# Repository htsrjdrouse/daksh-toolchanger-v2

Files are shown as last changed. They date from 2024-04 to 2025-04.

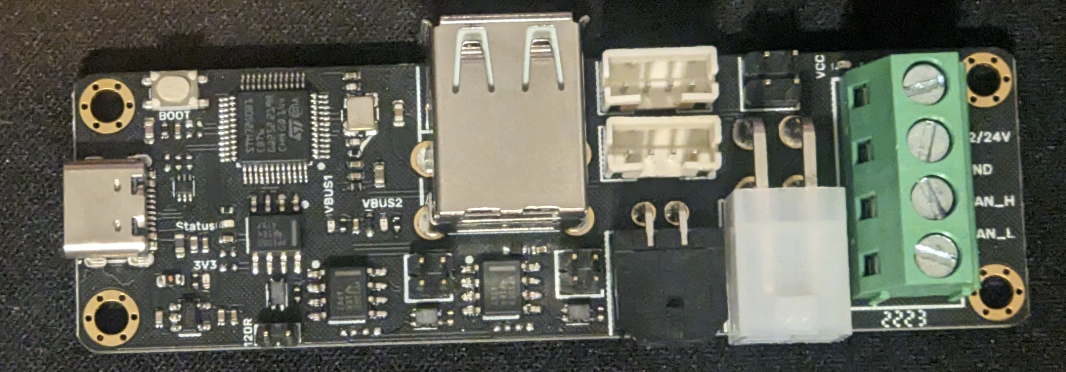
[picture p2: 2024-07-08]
Klipper/doc/btt_u2c_brd.png

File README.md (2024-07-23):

<b>Daksh modifications</b>

This version has a few modifications which were made in order to get it to work. The CAD design was modified using OpenScad and the code is included. Here is a list of various modifications:

1. Dock is modified so that it is rigid and accomodates the guide pins that adhere to the 2 in 1 rule for linear motion. The extruder assembly has been modified as well to match. There are more magnets to better secure the docking. 
2. Most (almost all) heat inserts have been replaced with self tapping holes.
3. Hall sensors have been replaced using mechanical endstops. This simplifies the wiring. 
4. The extruder has been redesigned to work with Bambu Labs hotend.
5. The z probe feature inside the extruder has been removed.
6. The maxwell coupling acorn nuts and mgn12 rails are 3-D printed.
7. The top rear extruder plate that secures the stepper motor has been redesigned that allows for better wiring organization.
8. Adjustable ooze wipes and adapted voron style spool holders

HTS Resources ToolChanger (https://www.youtube.com/watch?v=mFz-xJRdldU)

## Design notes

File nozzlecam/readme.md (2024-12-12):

This was originally a stroboscope but could be modified to work as a nozzlecam. It is based on the arducam. 



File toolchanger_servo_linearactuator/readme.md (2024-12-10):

Before working on this toolchanger project, I was focused on modifying 3D printers to function as liquid handlers for a laboratory automation applications. While doing this, I developed a tube loading/filling application that was apart of a nucleic acid detection assay which I documented <a href=https://www.htsresources.com/posts/Nucleic_acid_detection_PCR_Taqman_Probe_modified_3D_Printer/index.php> https://www.htsresources.com/posts/Nucleic_acid_detection_PCR_Taqman_Probe_modified_3D_Printer/index.php</a>. 

My interest with toolchangers is to create a "swiss army knife" of use case applications and I want to port over this application as being my first attempt to expand its utility. So I created a combined nozzle mount and linear actuator for the purposes of loading and unloading pipette tips. I haven't tested this design yet. While the original design employed a 8 pipette multichannel, this project involves focusing on a single nozzle.

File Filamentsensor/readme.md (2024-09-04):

The filament sensor is derived from https://www.printables.com/model/489791-smart-filament-sensor but modified to fit with the tool changer design. 

smart_filament_sensor_pic

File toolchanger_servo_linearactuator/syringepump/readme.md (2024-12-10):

I have been modifying the poseidon syringe pump (<a href=https://github.com/pachterlab/poseidon>https://github.com/pachterlab/poseidon</a>) So that it can work with a 1ml syringe pump.

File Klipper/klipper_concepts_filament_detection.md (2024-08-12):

# Filament sensors #

Testing the Sensors
1. Enable the sensors:
Run the macro TURN_ON_ALL_FILAMENT_SENSORS in your Klipper console.
2. Query individual sensors:
Use the QUERY_FILAMENT_SENSOR command with the sensor name:

```
QUERY_FILAMENT_SENSOR SENSOR=encoder_t0
QUERY_FILAMENT_SENSOR SENSOR=encoder_t1
```
3. Test sensor response:
Move filament through the sensor and run the query again to see if the state changes.

The code that controls this is filament_sensors.cfg. This is a set up for 2 tools. The key is to make sure TURN_ON_ALL_FILAMENT_SENSORS is in the start gcode. The PAUSE_AND_ALERT_FILAMENT macro will be modified so that PAUSE is changed to PAUSE_RESUME. ENABLE_FILAMENT_SENSOR is called by toolchanger.cfg through the gcode_macro SUB_TOOL_PICKUP_END. ENABLE_FILAMENT_SENSOR calls SET_FILAMENT_SENSOR which is a standard klipper function that is used to configure and control filament sensors, such as filament presence, detection, and runtime monitoring

```
[filament_motion_sensor encoder_t0]
switch_pin: EBB0: PB5
detection_length: 10
extruder: extruder
pause_on_runout: True
insert_gcode:
runout_gcode:
 PAUSE_AND_ALERT_FILAMENT T=0 STATE=JAM  

[filament_motion_sensor encoder_t1]
switch_pin: EBB1: PB5
detection_length: 10
extruder: extruder1
pause_on_runout: True
insert_gcode:
runout_gcode:
 PAUSE_AND_ALERT_FILAMENT T=1 STATE=JAM  

[gcode_macro TURN_ON_ALL_FILAMENT_SENSORS]
gcode:
        SET_FILAMENT_SENSOR SENSOR=encoder_t0 ENABLE=1
        SET_FILAMENT_SENSOR SENSOR=encoder_t1 ENABLE=1
        M118 ENABLE ALL FILAMENT_SENSORS

[gcode_macro TURN_OFF_ALL_FILAMENT_SENSORS]
gcode:
        SET_FILAMENT_SENSOR SENSOR=encoder_t0 ENABLE=0
        SET_FILAMENT_SENSOR SENSOR=encoder_t1 ENABLE=0
        M118 DISABLE ALL FILAMENT_SENSORS

[gcode_macro ENABLE_FILAMENT_SENSOR]
gcode:
  {% if params.T|int > 0 and params.T|int < 5 %}
         SET_FILAMENT_SENSOR SENSOR=encoder_t{params.T} ENABLE=1
         M118 ENABLE FILAMENT SENSOR T{params.T}
  {% endif %}

[gcode_macro PAUSE_AND_ALERT_FILAMENT]
gcode:
        M117 TOOLHEAD T{params.T} {params.STATE}
        SET_PAUSE_TYPE TYPE=2 # Set Pause Type to Filament
        SET_STATUS_LED_ERROR_START T={params.T}
        SET_ENCLOSURE_ERROR_START
        PAUSE
```

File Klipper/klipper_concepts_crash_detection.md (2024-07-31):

# Concepts about klipper programming environment as it relates to tool changing and crash_detection. #

Crash detection is important to ensure that the toolchanging is working, crash_detection.cfg controls this process, it is set up so that you can verify the toolchange during print after toolchanging after a specified time duration. 

## SAVE_GCODE_STATE ##

In Klipper, SAVE_GCODE_STATE is a command that saves the current state of the G-code parser, allowing the printer to resume a print job from the exact position where it was paused or interrupted.

When SAVE_GCODE_STATE is executed, Klipper saves the following information:

1. Current G-code line number
2. Current G-code command (e.g., G1, G28, etc.)
3. Current coordinates (X, Y, Z, E)
4. Current extruder temperature
5. Current bed temperature

This saved state allows Klipper to resume the print job from the exact position where it was paused or interrupted, ensuring that the print continues correctly.
SAVE_GCODE_STATE is typically used in conjunction with LOAD_GCODE_STATE to resume a print job after a pause or interruption. The workflow is as follows:
SAVE_GCODE_STATE saves the current state before pausing or interrupting the print.
The print is paused or interrupted (e.g., due to a tool change, error, or manual pause).
LOAD_GCODE_STATE loads the saved state, restoring the printer to the exact position where it was paused or interrupted.
The print resumes from the loaded state.
By using SAVE_GCODE_STATE and LOAD_GCODE_STATE, Klipper ensures that print jobs can be resumed accurately and reliably, even after interruptions or pauses.

SAVE_GCODE_STATE is called gcode_macros.cfg, toolchanger.cfg, klipper_toolchanger/M600.cfg and klipper_toolchanger/pause_resume.cfg: 

### gcode_macros.cfg ###

```
gcode_macros.cfg:    SAVE_GCODE_STATE NAME=PRIME_LINE_state
gcode_macros.cfg:    SAVE_GCODE_STATE NAME=BEFORE_CLEAN
gcode_macros.cfg:    SAVE_GCODE_STATE NAME=PURGE_state
```

### klipper_toolchanger/M600.cfg ###

```
klipper_toolchanger/M600.cfg:  SAVE_GCODE_STATE NAME=M600_state
```

### klipper_toolchanger/pause_resume.cfg ###

```
klipper_toolchanger/pause_resume.cfg:   SAVE_GCODE_STATE NAME=PAUSE_state
klipper_toolchanger/pause_resume.cfg:	 	SAVE_GCODE_STATE NAME=PAUSE_state
```

### toolchanger.cfg ###

```
toolchanger.cfg:  SAVE_GCODE_STATE NAME=tool_unlock_state                                         # Save gcode state
toolchanger.cfg:  SAVE_GCODE_STATE NAME=tool_lock_state                                           # Save gcode state
toolchanger.cfg:  SAVE_GCODE_STATE NAME=TOOL_PICKUP                                    # Save GCODE state. Will be restored at the end of SUB_TOOL_PICKUP_END
toolchanger.cfg:  SAVE_GCODE_STATE NAME=TOOL_DROPOFF_002                        # Save GCode state. 
```

LOAD_GCODE_STATE is not used in this software. 

## VERIFY_TOOLCHANGE_DURING_PRINT DURATION=30 FORCE=0 ##

In Klipper, when DURATION is specified in a command like VERIFY_TOOLCHANGE_DURING_PRINT DURATION=30 FORCE=0, it defines the verification window during which Klipper monitors the tool change process.
Here's how it works:

When the VERIFY_TOOLCHANGE_DURING_PRINT command is executed, Klipper starts monitoring the tool change process.

The DURATION parameter (in this case, 30 seconds) specifies the time window during which Klipper will verify the tool change.

The printer does not pause during this verification window. Instead, Klipper monitors the tool change process concurrently while the printer continues to move and execute G-code commands.

Within the 30-second verification window, Klipper checks the tool change status (e.g., sensor readings, tool presence, etc.) to ensure the tool change is successful.

If the verification fails within the 30-second window (e.g., sensors indicate an error), Klipper will pause the print and wait for manual intervention (due to FORCE=0).

In summary, the DURATION parameter defines the time window during which Klipper verifies the tool change process, but it does not cause the printer to pause. The verification occurs concurrently with the print job, allowing the printer to continue moving while Klipper monitors the tool change.

So if you printer is fails after loading and docking tools you may want to extend the DURATION. 

FORCE=0: This parameter controls the behavior if the tool change verification fails. A value of 0 means that if the verification fails, the print will pause and wait for manual intervention to resume. If FORCE were set to 1, the print would abort instead of pausing.

```
[gcode_macro VERIFY_TOOLCHANGE_DURING_PRINT]
        gcode:
                M118 "VERIFY_TOOLCHANGE_DURING_PRINT in {params.DURATION} seconds with printer state: {printer.idle_timeout.state} FORCE: {params.FORCE}"
                {% if printer.idle_timeout.state == "Printing" or params.FORCE|int == 1 %}
                        M118 "EXECUTING VERIFY_TOOLCHANGE_DURING_PRINT in {params.DURATION} seconds"
                        UPDATE_DELAYED_GCODE ID=_DELAYED_CHECK_MACHINE_STATE_QUICK DURATION=0
                        UPDATE_DELAYED_GCODE ID=_DELAYED_CHECK_MACHINE_STATE_QUICK DURATION={params.DURATION}
                {% endif %}
```

Let's break down this macro:

Macro Name: VERIFY_TOOLCHANGE_DURING_PRINT

Purpose: This macro verifies a tool change during a print job, ensuring the printer is in a safe state.
G-code:

M118 "VERIFY_TOOLCHANGE_DURING_PRINT in {params.DURATION} seconds with printer state: {printer.idle_timeout.state} FORCE: {params.FORCE}":

Prints a message to the console indicating the start of the verification process, including the duration, printer state, and force setting.

{% if printer.idle_timeout.state == "Printing" or params.FORCE|int == 1 %}:

Conditional statement that checks two conditions:
printer.idle_timeout.state == "Printing": If the printer is currently printing.
params.FORCE|int == 1: If the FORCE parameter is set to 1 (abort print on failure).
If either condition is true, the code inside the {% if %} block is executed.

M118 "EXECUTING VERIFY_TOOLCHANGE_DURING_PRINT in {params.DURATION} seconds":
Prints a message to the console indicating the verification process is executing.

UPDATE_DELAYED_GCODE ID=_DELAYED_CHECK_MACHINE_STATE_QUICK DURATION=0:
Resets a delayed G-code command ( _DELAYED_CHECK_MACHINE_STATE_QUICK ) to execute immediately ( DURATION=0 ).

UPDATE_DELAYED_GCODE ID=_DELAYED_CHECK_MACHINE_STATE_QUICK DURATION={params.DURATION}:
Updates the delayed G-code command to execute after the specified duration ( {params.DURATION} seconds).

In summary, this macro:

1. Prints a message indicating the start of the verification process.
2. Checks if the printer is printing or if FORCE is set to 1.
3. If the conditions are met, it prints a message indicating the verification is executing and updates a delayed G-code command to execute after the specified duration.
The delayed G-code command (_DELAYED_CHECK_MACHINE_STATE_QUICK) is defined elsewhere in the Klipper configuration and performs a quick machine state check. If the verification fails, the print will be paused or aborted, depending on the FORCE setting.

## _DELAYED_CHECK_MACHINE_STATE_QUICK ##

```
[delayed_gcode _DELAYED_CHECK_MACHINE_STATE_QUICK]
initial_duration: 0
gcode:
        #M118 "Evaluating Machine State"
        _EVALUATE_MACHINE_STATE_QUICK
        {% if printer.idle_timeout.state == "Printing" %}
                VERIFY_TOOLCHANGE_DURING_PRINT DURATION=5 FORCE=0
        {% endif %}
```

Macro Name: _DELAYED_CHECK_MACHINE_STATE_QUICK

Type: Delayed G-code macro

Purpose: This macro checks the machine state and verifies tool changes during printing.

Configuration:

initial_duration: 0: The macro is initially set to execute immediately (0 seconds delay).

G-code:

#M118 "Evaluating Machine State": A commented-out line that would print a message to the console if uncommented.
_EVALUATE_MACHINE_STATE_QUICK: Calls another macro (not shown here) that quickly evaluates the machine state.

{% if printer.idle_timeout.state == "Printing" %}: Conditional statement that checks if the printer is currently printing.
VERIFY_TOOLCHANGE_DURING_PRINT DURATION=5 FORCE=0: If the printer is printing, this line executes the VERIFY_TOOLCHANGE_DURING_PRINT macro (explained earlier) with:
DURATION=5: Verification window of 5 seconds.
FORCE=0: Pause print on failure, don't abort.

In summary, this macro:

Evaluates the machine state quickly.

If the printer is printing, it verifies tool changes during the next 5 seconds.

If verification fails, the print will be paused (due to FORCE=0).

This macro is likely used in conjunction with the previous one to create a delayed verification process. The UPDATE_DELAYED_GCODE commands in the previous macro update the execution time of this macro, allowing it to run at a later time (e.g., after a tool change).

## Delayed G-code macros ##

In Klipper, a Delayed G-code macro is a type of macro that allows you to execute G-code commands at a later time, rather than immediately.

Key characteristics:

Delayed execution: Delayed G-code macros are executed after a specified delay time, which can be set using the initial_duration parameter or updated using the UPDATE_DELAYED_GCODE command.

G-code commands: Delayed G-code macros contain G-code commands, just like regular macros, but they are executed at a later time.

Async execution: Delayed G-code macros are executed asynchronously, meaning they don't block the execution of other macros or G-code commands.

Use cases:

Tool change verification: Verify tool changes after a short delay to ensure the tool is properly seated and ready for use.

Machine state checks: Check the machine state (e.g., temperature, position) after a delay to ensure everything is stable before proceeding.

Timed actions: Perform actions at specific times during a print, such as retracting the filament at a certain height.

Syntax:
Delayed G-code macros are defined using the following syntax:

```
[delayed_gcode <macro_name>]
initial_duration: <delay_time>
gcode:
  # G-code commands to execute after the delay
```

Replace <macro_name> with the name of your macro, <delay_time> with the initial delay time (in seconds), and add your G-code commands under the gcode section.

By using delayed G-code macros, you can create complex workflows and automate tasks that require timed execution, making your 3D printing experience more efficient and reliable.

## _EVALUATE_MACHINE_STATE_QUICK ##

This is the logic that evaluates the each of the tool coupling and docking sensors. 

```
[gcode_macro _EVALUATE_MACHINE_STATE_QUICK]
gcode:
  {% set allTools = printer["gcode_macro VARIABLES_LIST"].tools %}
  {% set activeTools = [] %}
  {% set accountedTools = [] %}
  #M118 "--->_EVALUATE_MACHINE_STATE_QUICK"
  {% for tool in allTools %}
          #We do both mechanical endstops individually to catch the case where carriage is sitting flush with a tool while it is still in dock
          {% if printer["atc_switch tc"~tool].state == "PRESSED" %}
                  {activeTools.append(tool|int) or ""}
                  {accountedTools.append(tool) or ""}
          {% endif %}
          {% if printer["atc_switch td"~tool].state == "PRESSED" %}
                        {accountedTools.append(tool) or ""}
          {% endif %}
  {% endfor %}
  #M118 Active Tools {activeTools}
  #M118 Account Tools {accountedTools}
  #M118 All Tools {allTools}
  {% if accountedTools|length !=  allTools|length or printer["gcode_macro VARIABLES_LIST"].tc_state == -1 %}
         #Error Detected
         #M118 "Tools Mismatch"     
        _EVALUATE_MACHINE_STATE
  {% else %}
        # Check if Active Tool has changed
        #M118 Active Tools {activeTools}
        {% if activeTools|length > 0 %}
                {% set active_tool = activeTools[0]|int %}
        {% else %}
                {% set active_tool = -1 %}
        {% endif %}
        #M118 "Active Tool {active_tool}"
        {% if active_tool != printer["gcode_macro VARIABLES_LIST"].active_tool %}
                 #M118 "Active Tool has Changed"            
             _EVALUATE_MACHINE_STATE
        {% endif %}
  {% endif %}
```

## _EVALUATE_MACHINE_STATE ##

This is the more thorough analysis of the coupling and docking sensors. The first part sets the variables data (active_tool, tc_state and tc_error_code). The second part sets the LED status color and calls the SET_ENCLOSURE_ERROR_START (enclosure LEDs are not set up on current system and should be commented out) and PAUSE_AND_ALERT macros. 

```
[gcode_macro _EVALUATE_MACHINE_STATE]
gcode:
  {% set allTools = printer["gcode_macro VARIABLES_LIST"].tools %}
  {% set activeTools = [] %}
  {% set dockedTools = [] %}
  {% set accountedTools = [] %}
  {% set errorTools = [] %}
  {% for tool in allTools %}
        #Find All Tools attached to the carriage - should be only 1
        {% if printer["atc_switch tc"~tool].state == "PRESSED" %}
                {activeTools.append(tool|int) or ""}
                {accountedTools.append(tool|int) or ""}
        {% endif %}
        #Find All Tools attached to the docks - should be maximum num tools               
        {% if printer["atc_switch td"~tool].state == "PRESSED" %}
                {dockedTools.append(tool|int) or ""}
                {accountedTools.append(tool|int) or ""}
        {% endif %}
  {% endfor %}
  #Ensure each tool only shows up either in active or docked list - if not, throw error with the specific tool
  #M118 Active Tools {activeTools}
  #M118 Docked Tools {dockedTools}
  {% if (activeTools|length|int <= 1) and (activeTools|length + dockedTools|length ==  allTools|length ) %}

                #All Is Well- all tools are accounted for 
                M118 "All Tools Accounted For - Proceeding with Normal Startup"
                {% if activeTools|length > 0 %}
                        SET_GCODE_VARIABLE MACRO=VARIABLES_LIST VARIABLE=active_tool VALUE={activeTools[0]}
                {% else %}
                        SET_GCODE_VARIABLE MACRO=VARIABLES_LIST VARIABLE=active_tool VALUE=-1 #No Tool Attached
                {% endif %}
                SET_GCODE_VARIABLE MACRO=VARIABLES_LIST VARIABLE=tc_state VALUE=0
                SET_GCODE_VARIABLE MACRO=VARIABLES_LIST VARIABLE=tc_error_code VALUE=0
  {% else %}
                #Check if multiple tools are showing up as attached to carriage - could be an issue with the carriage attach hall effect sensor on a docked tool returning a success
                  {% if (activeTools|length == 0) and (dockedTools|length <  allTools|length ) %}

                        # A Tool should be attached to the carriage but isnt - maybe it has fallen off during printing
                        M118 " A Tool should be attached to the carriage but No Tool is present"
                        {% set allToolsTemp = allTools %}
                        {% for tool in accountedTools %}
                                {allToolsTemp.pop(allToolsTemp.index(tool))}
                        {% endfor %}

                        {% for tool in allToolsTemp %}
                                {errorTools.append(tool) or ""}
                        {% endfor %}
                        SET_GCODE_VARIABLE MACRO=VARIABLES_LIST VARIABLE=tc_state VALUE=-1
                        SET_GCODE_VARIABLE MACRO=VARIABLES_LIST VARIABLE=tc_error_code VALUE=1
                  {% else %}
                        {% if activeTools|length > 1 %}
                                {% set allToolsTemp = allTools %}
                                M118 "Multiple Tools Showing up as attached to carriage"
                                {% for tool in activeTools %}
                                        {% if printer["atc_switch tc"~tool].state == "PRESSED" and printer["atc_switch td"~tool].state == "PRESSED" %}
                                                {errorTools.append(tool) or ""}
                                        {% endif %}
                                {% endfor %}
                                SET_GCODE_VARIABLE MACRO=VARIABLES_LIST VARIABLE=tc_state VALUE=-1
                                SET_GCODE_VARIABLE MACRO=VARIABLES_LIST VARIABLE=tc_error_code VALUE=3
                        {% else %}
                                # Check if any tools shows up in both active and docked lists - possible if the carriage is sitting flush with a tool while it is still in dock
                                {% if activeTools|length + dockedTools|length > allTools|length and printer["gcode_macro VARIABLES_LIST"]["print_status"]|int != 1 %}
                                        M118 "Error: Tools are showing up in both active and docked list"
                                        {% set dockedToolsTemp = dockedTools %}
                                        {% for tool in activeTools %}
                                                        {errorTools.append(dockedToolsTemp.pop(dockedToolsTemp.index(tool))) or ""}
                                        {% endfor %}
                                        SET_GCODE_VARIABLE MACRO=VARIABLES_LIST VARIABLE=tc_state VALUE=-1
                                        SET_GCODE_VARIABLE MACRO=VARIABLES_LIST VARIABLE=tc_error_code VALUE=4   
                                        {% else %}
                                                #Check if any of the tools supposed to be docked is not properly seated in the dock
                                                {% if dockedTools|length !=  allTools|length - 1 %}
                                                                M118 "Mismatch in number of tools docked"
                                                                {% set allToolsTemp = allTools %}
                                                                {% for tool in accountedTools %}
                                                                        {allToolsTemp.pop(allToolsTemp.index(tool))}
                                                                {% endfor %}
                                                                {% for tool in allToolsTemp %}
                                                                        {errorTools.append(tool) or ""}
                                                                {% endfor %}
                                                                SET_GCODE_VARIABLE MACRO=VARIABLES_LIST VARIABLE=tc_state VALUE=-1
                                                                SET_GCODE_VARIABLE MACRO=VARIABLES_LIST VARIABLE=tc_error_code VALUE=2

                                                {% endif %}
                                        {% endif %}
                        {% endif %}
                {% endif %}
{% endif %}
  {% if errorTools|length > 0 %}
        # Error Tools Found  - set the LEDS on error tools and enclosure to the ERROR state
        M118 "Error Tools: " {errorTools}
        {% for tool in errorTools %}
           #Blink STATUS LEDS on the Error Tools
                SET_STATUS_LED_ERROR_START T={tool}
        {% endfor %}
        SET_ENCLOSURE_ERROR_START
        PAUSE_AND_ALERT
  {% else %}

          # All Checked out - set the LEDS on all tools and enclosure to the default ALL OK state
          {% if activeTools|length > 0 %}
                {% for tool in activeTools %}
                        #M118 "Set Active Tool {tool}"
                        SET_STATUS_LED_LOCK T={tool}
                        _SET_CURRENT_TOOL T={tool}
                {% endfor %}
          {% else %}
                         # M118 "Set Active Tool {tool}"
                        _SET_CURRENT_TOOL T=-1
          {% endif %}

          {% for tool in dockedTools %}
                {% if printer["gcode_macro VARIABLES_LIST"]["print_status"]|int == 1%}
                        {% if printer["gcode_macro VARIABLES_LIST"]["t"~tool~"_used_in_print"]|int == 1%}
                                SET_STATUS_LED_DOCK T={tool}
                        {% else %}
                                SET_STATUS_LED_NOT_IN_USE T={tool}
                        {% endif %}
                {% else %}
                                SET_STATUS_LED_DOCK T={tool}                    
                {% endif %}
          {% endfor %}

          SET_ENCLOSURE_DEFAULT

  {% endif %}
```

## PAUSE_AND_ALERT ##

```
[gcode_macro PAUSE_AND_ALERT]
gcode:                  
        SET_PAUSE_TYPE TYPE=1 # Set Pause Type to Toolchanger State Error
        PAUSE           
```

The problem with the PAUSE macro is that when the condition is not met, PAUSE is called temporarily, and when the condition is met, it resumes automatically without requiring user intervention.

## SET_PAUSE_TYPE ##

```
[gcode_macro SET_PAUSE_TYPE]
gcode:
        SET_GCODE_VARIABLE MACRO=VARIABLES_LIST VARIABLE=pause_type VALUE={params.TYPE}
 ```

SET_GCODE_VARIABLE is a standard Klipper function. It's used to set or modify variables within G-code macros.

Here's what this macro does:

1. [gcode_macro SET_PAUSE_TYPE]: This line defines a new G-code macro named SET_PAUSE_TYPE.
2. SET_GCODE_VARIABLE: This is the Klipper command used to set or modify a variable within a macro.
3.  MACRO=VARIABLES_LIST: This specifies that we're setting a variable in a macro named VARIABLES_LIST. This is likely another macro defined elsewhere in the configuration that stores various variables.
4.  VARIABLE=pause_type: This is the name of the variable we're setting or modifying within the VARIABLES_LIST macro.
5.  VALUE={params.TYPE}: This sets the value of the pause_type variable. The {params.TYPE} syntax means it's taking the value of the TYPE parameter passed when calling the SET_PAUSE_TYPE macro.

## VARIABLES_LIST ##

This is in crash_detection.cfg:

```
#Check and Verify Initial Status of the tools upon startup in comparison to the one reported by the TC system based on SAVED VVARIABLES_LISTARIABLES
  
[gcode_macro VARIABLES_LIST]
variable_tools:[0,1]
variable_active_tool:-1
variable_tc_state:0 #-1:Error, 0: Operational
variable_tc_error_code:0 # 0: No Error, 1: No Tool Attached to Carriage, 2: Tool Dock Failure, 3: Multiple Tools Attached  
variable_global_z_offset:0
variable_error_tools:[]
variable_t0_used_in_print:0
variable_t1_used_in_print:0
variable_print_status:0
variable_current_layer:0
variable_current_bed_temp:0
variable_pause_type:0 # 0: No Error, 1:ToolChanger Error 2: Filament Error
        
gcode:    

```

## PAUSE ##
The PAUSE macro has been modified to fix this, in klipper_toolchanger, pause_resume.cfg contains the PAUSE and RESUME macros. When looking at this code, the sensor error can be ToolChanger Error or a Filament Error. The error conditional should be > 0 rather than == 1 or you add an additional conditional to indicate the Filament Error. 

The standard klipper PAUSE function is renamed to BASE_PAUSE to discriminate between this custom macro and the standard klipper PAUSE function. 

```
[gcode_macro PAUSE]
rename_existing: BASE_PAUSE
gcode:
 {% if printer['pause_resume'].is_paused|int == 0 %}
   SET_GCODE_VARIABLE MACRO=RESUME VARIABLE=zhop VALUE=5  # Set Z-hop variable for RESUME
   SAVE_GCODE_STATE NAME=PAUSE_state
   BASE_PAUSE
   G91
   G1 Z5 F900
   G90
   ;TURN_OFF_HEATERS
   ;M106 S0
   SET_IDLE_TIMEOUT TIMEOUT=43200
   RSCS_off
   {% if error == 1 %}
     M117 Print paused due to sensor error
     # Additional error handling actions can be added here
   {% else %}
     M117 Print paused manually
   {% endif %}
 {% endif %}
```

## RESUME ##

The RESUME macro now goes back down to the original z height position before the pause.  This was modified by including an active tool conditional or you get an error when there is not tool loaded.

```
[gcode_macro RESUME]
rename_existing: BASE_RESUME
variable_zhop: 5
gcode:
  {% if printer.pause_resume.is_paused %}
	{% if printer["gcode_macro VARIABLES_LIST"].tc_state == 0 %}
	 	G91
		# Add Z-hop movement here
      	G1 Z-{zhop} F900  # Move Z back down by zhop amount
      	G90
	 	{% if printer["gcode_macro VARIABLES_LIST"]["print_status"]|int == 1 %}
			{% if printer["gcode_macro VARIABLES_LIST"]["pause_type"]|int == 1%}
				PREPARE_TOOL_BEFORE_RESUME
			{% endif %}
		{% endif %}
	 	RESTORE_GCODE_STATE NAME=PAUSE_state
	 	BASE_RESUME
	 	VERIFY_TOOLCHANGE_DURING_PRINT DURATION=5 FORCE=1
	 	SAVE_GCODE_STATE NAME=PAUSE_state
	 	RSCS_LAYER_CHECK LAYER={printer["gcode_macro VARIABLES_LIST"].current_layer}
		RESET_PAUSE_TYPE
		{% if printer["gcode_macro VARIABLES_LIST"].active_tool|int > -1 %}
		  SET_STATUS_LED_LOCK T={printer["gcode_macro VARIABLES_LIST"].active_tool}
		{% endif %}  
		SET_ENCLOSURE_DEFAULT
	{% else %}
		M118 "Printer in Error State - Cannot Resume Print"
	{% endif %}
  {% endif %}
```

## SUB_TOOL_PICKUP_END ##

In toolchanger.cfg, when the tool is loaded which is initiated in tool.py but eventually calls [toolgroup 0] and then SUB_TOOL_PICKUP_END when picking up a tool. The problem is that if error is not getting generated when it is incorrectly loaded/unloaded quickly enough, the VERIFY_TOOLCHANGE_DURING_PRINT DURATION=30 FORCE=0 is removed (commented out).  

```
[gcode_macro SUB_TOOL_PICKUP_END]
description: Internal subroutine. Do not use!
# Tnnn: Tool to pickup
gcode:

   {%set myself = printer['tool '~params.T]%}
   {% set lock_x = printer.save_variables.variables['t'~params.T~'_lock_x'] %}
   {% set lock_y = printer.save_variables.variables['t'~params.T~'_lock_y'] %}
   {%set global_offset_z =  printer["gcode_macro VARIABLES_LIST"].global_z_offset|float %}
   
   {% if 't0_x_offset' not in printer.save_variables.variables %}
      {%set offset_x =  0 %}
      {%set offset_y =  0 %}
      {%set offset_z = 0 %}  
  {% else %}
      {%set offset_x =  printer.save_variables.variables['t'~params.T~'_x_offset']|float%}
      {%set offset_y =  printer.save_variables.variables['t'~params.T~'_y_offset']|float%}
      {% if params.T|int > 0 %}
        {%set offset_z =  printer.save_variables.variables['t0_z_offset']|float + printer.save_variables.variables['t'~params.T~'_z_offset']|float + global_offset_z|float %}
      {% else %}
        {%set offset_z =  printer.save_variables.variables['t'~params.T~'_z_offset']|float %}
      {% endif %}    
  {% endif %}

  M118 T{params.T}
  M118 OFFSET X: {offset_x}
  M118 OFFSET Y: {offset_y}
  M118 OFFSET Z: {offset_z}
     
  ##############  Move out to zone  ##############
  #G0 Y{myself.zone[1]|int - 50} F{printer.save_variables.variables['ktcc_speed1']|int}
  G0 Y{lock_y|int - 120} F{printer.save_variables.variables['ktcc_speed1']|int}
  RESTORE_ACCELERATION 
  SET_GCODE_OFFSET X={offset_x|float} Y={offset_y|float} Z={offset_z|float} MOVE=1  # Set X and Y offsets, 
  SET_ACTIVE_TOOL_PROBE T={params.T}
  SET_STATUS_LED_LOCK T={params.T}
  G92 E0
  #{% if printer["gcode_macro TOOL_USE_COUNT"]['t'~params.T~'_use_count'] > 0 %}
  ##Enable Specific Tool Filament Sensor  
  ENABLE_FILAMENT_SENSOR T={params.T}
  #{% endif %}
  INCREMENT_TOOL_USE_COUNT T={params.T}
  #Move to the last position of toolhead before toolchange
  {% if printer["gcode_macro STORE_TOOLHEAD_POSITION"].toolhead_pos_stored|int == 1  and printer["gcode_macro STORE_TOOLHEAD_POSITION"].bypass_toolhead_position|int == 0 %}
     M118 Move to old toolhead position
     G1 X{printer["gcode_macro STORE_TOOLHEAD_POSITION"].toolhead_x} Y{printer["gcode_macro STORE_TOOLHEAD_POSITION"].toolhead_y} F{printer.save_variables.variables['ktcc_speed1']|int}
  {% endif %}
  CLEAR_TOOLHEAD_POSITION
  ;G4 P2000  ; Wait for 2 seconds
  M400
  #VERIFY_TOOLCHANGE_DURING_PRINT DURATION=30 FORCE=0
  TOOLCHANGE_Z_MOVE_END
 ```

## SUB_TOOL_DROPOFF_END ##

Sometimes, after unloading the tool the error gets triggered to early, so to delay it, VERIFY_TOOLCHANGE_DURING_PRINT DURATION=5 was added after the final move with a 5 second delay.

```
[gcode_macro SUB_TOOL_DROPOFF_END]
description: Internal subroutine. Do not use!
gcode:
  {%set myself = printer['tool '~params.T]%}
  
  SET_STATUS_LED_DOCK T={params.T}
  
  RESTORE_GCODE_STATE NAME=TOOL_DROPOFF_002 MOVE=0   # Restore Gcode state
  RESTORE_ACCELERATION                # Restore saved acceleration value.	
  
  #added this to improve reliability 
  M400
  VERIFY_TOOLCHANGE_DURING_PRINT DURATION=5 FORCE=0 #Delayed GCode to Verify Successful toolchange during a print 
    
```

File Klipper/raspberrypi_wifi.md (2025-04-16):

This installs klipper on a rasppi (called clientPi) so that the Rasppi running klipper (called klipperPi) can get access to the clientPi's gpio pins. 

1. git clone https://github.com/Klipper3d/klipper.git
cd klipper

2. make menuconfig
Select linux process and Enable extra low-level configuration options   
make clean
make

4. ls -l /home/[username]/klipper/out/klipper.elf
5. test it /home/[username]/klipper/out/klipper.elf -I /tmp/klipper_host_mcu_camera_pi
6. If it runs and creates /tmp/klipper_host_mcu_camera_pi, it’s functionally klipper_mcu. Rename it: mv /home/[username]/klipper/out/klipper.elf /home/[username]/klipper/out/klipper_mcu
chmod +x /home/[ussername]/klipper/out/klipper_mcu
7. Edit service file sudo nano /etc/systemd/system/klipper-mcu.service:

[Unit]
Description=Klipper MCU Service for Camera Pi
After=network-online.target
Wants=network-online.target

[Service]
Type=simple
User=[username]
ExecStart=/home/[username]klipper/out/klipper_mcu -I /tmp/klipper_host_mcu_camera_pi
Restart=always
RestartSec=5

[Install]
WantedBy=multi-user.target

7. sudo systemctl daemon-reload
sudo systemctl restart klipper-mcu.service
sudo systemctl status klipper-mcu.service
ls /tmp/klipper_host_mcu*

8. Edit printer.cfg
[mcu camera_pi]
serial: /tmp/klipper_host_mcu_camera_pi

9. On the klipperPi set up ssh keys (e.g., ssh-copy-id to clientPi)
    
10. Create a ssh tunnel as a bash shell script that looks like this. Puyt this on the klipperPi (I call the script camera_control.sh &):
```
#!/bin/bash

# Remove stale socket file if it exists
if [ -e /tmp/klipper_host_mcu_camera_pi_local ]; then
    sudo rm /tmp/klipper_host_mcu_camera_pi_local
fi

ssh -N -L /tmp/klipper_host_mcu_camera_pi_local:/tmp/klipper_host_mcu_camera_pi pi@192.168.1.161
```
11. Autostart Script on Camera Pi
Add the script to /etc/rc.local for startup:

bash
sudo nano /etc/rc.local
Add before exit 0:

text
python /home/username/camera_control.sh &

Assign GPIO pins

GPIO18 for the LED, GPIO23 for the dock sensor, GPIO24 for the carriage sensor

#12. Here is the recipe for installing camera-streamer

13. Updated installation steps:

First, let's clean up the current directory and start fresh:

cd ~
rm -rf camera-streamer

Clone the repository with submodules:
```
git clone --recursive https://github.com/ayufan/camera-streamer.git
cd camera-streamer
```
If you've already cloned without the --recursive flag, initialize and update the submodules:
```
git submodule update --init --recursive
```
Install additional dependencies:
```
sudo apt install -y libcamera-dev liblivemedia-dev libssl-dev libboost-dev libboost-program-options-dev libboost-system-dev libdrm-dev
```
Now attempt to build again:
```
sed -i 's/-Werror//g' Makefile
sudo apt install -y xxd
sudo apt install -y cmake
sudo apt install -y build-essential pkg-config
make
```
After successful build, install:
```
sudo make install
```
14. You need to open up the firewall for the port 8080

```
sudo apt install ufw
sudo ufw allow 8080
```

15. Then run the command:
```
camera-streamer   --camera-path=/base/soc/i2c0mux/i2c@1/imx519@1a   --camera-type=libcamera   --camera-width=1920   --camera-height=1080   --camera-fps=30   --camera-options=--autofocus-mode=continuous   --http-listen=0.0.0.0   --http-port=8080   --camera-format=MJPG
```
Then go to your browser and enter the right ip address:
http://[ip address]:8080/

Now install crowsnest, first download kiauh
```
git clone https://github.com/dw-0/kiauh.git
./kiauh/kiauh.sh
```
Install crowsnest using it, I cannot figure out how to install crowsnest but you can get mainsail to work with camera-streamer instead. 

Here's how to update your Klipper configuration:

On your main Raspberry Pi that runs Klipper (not the camera Pi), you'll need to update the webcam configuration.
If you're using Mainsail, go to the Mainsail interface in your browser and navigate to the "Settings" tab.
Look for the "Webcams" section and add or modify the camera configuration:

Name: Your camera name (e.g., "Printer Cam")
URL: http://[camera-pi-ip]:8080/stream (replace [camera-pi-ip] with the actual IP address)
Service: Custom
Target FPS: 30
Flip Horizontal/Vertical: as needed

This worked:
Here's how to configure it in Mainsail's UI:

```
In the Mainsail interface, go to "Settings" → "Webcams"
Click "Add Webcam"
Configure as follows:

Name: Printer Cam
Service: mjpeg-streamer
Stream URL: http://[camera-pi-ip]:8080/stream
Snapshot URL: http://[camera-pi-ip]:8080/snapshot
Target FPS: 30
Flip options: as needed
```

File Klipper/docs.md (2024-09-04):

# daksh toolchanger docs

This configuration is for just 2 tools and there is just 1 detachable z sensor probe. Process data is stored in variables.cfg which is not documented

## printer.cfg calls toolchanger.cfg that contains the toolchanger action
- https://github.com/htsrjdrouse/daksh-toolchanger-v2/blob/main/Klipper/config/printer_docs.md
- https://github.com/htsrjdrouse/daksh-toolchanger-v2/blob/main/Klipper/config/toolchanger_docs.md

## toolchanger.cfg calls the rest of the files to create the process
- https://github.com/htsrjdrouse/daksh-toolchanger-v2/blob/main/Klipper/config/calibrate-offsets_docs.md
- https://github.com/htsrjdrouse/daksh-toolchanger-v2/blob/main/Klipper/config/crash_detection_docs.md
- https://github.com/htsrjdrouse/daksh-toolchanger-v2/blob/main/Klipper/config/dock_calibrate_docs.md
- https://github.com/htsrjdrouse/daksh-toolchanger-v2/blob/main/Klipper/config/status_led_docs.md
- https://github.com/htsrjdrouse/daksh-toolchanger-v2/blob/main/Klipper/config/filament_sensors_docs.md <-- no longer used replaced by smart_filament_sensors
- https://github.com/htsrjdrouse/daksh-toolchanger-v2/blob/main/Klipper/config/smart_filament_sensors_docs.md
- https://github.com/htsrjdrouse/daksh-toolchanger-v2/blob/main/Klipper/config/tool_usage_docs.md
## The klipper_toolchanger directory contains KTCC (https://github.com/TypQxQ/Klipper_ToolChanger/tree/master) gcodes 
- https://github.com/htsrjdrouse/daksh-toolchanger-v2/blob/main/Klipper/config/klipper_toolchanger/toolchange_management_docs.md
Are these .cfgs originally from ktcc?
- https://github.com/htsrjdrouse/daksh-toolchanger-v2/blob/main/Klipper/config/klipper_toolchanger/pause_resume_docs.md
- https://github.com/htsrjdrouse/daksh-toolchanger-v2/blob/main/Klipper/config/klipper_toolchanger/misc_docs.md
- https://github.com/htsrjdrouse/daksh-toolchanger-v2/blob/main/Klipper/config/klipper_toolchanger/ktcc_readme.md
## The tools are put in the tools directory
- https://github.com/htsrjdrouse/daksh-toolchanger-v2/blob/main/Klipper/config/tools/tool_0.cfg
- https://github.com/htsrjdrouse/daksh-toolchanger-v2/blob/main/Klipper/config/tools/tool_1.cfg

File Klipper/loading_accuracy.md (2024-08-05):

##Testing loading accuracy##

I wanted to see how accurate the loading and unloading is and used the nudge tool (https://github.com/zruncho3d/nudge/tree/main). When first using this tool, I made some mistakes first I installed it upside down then maybe I didn't tighten the screws sufficiently to get a good electrical connection. I ended up having to tweak a few settings from what is recommended in the github, not entirely sure its necessary. 

Here are my settings for the nudge tool (found in calibrate-offsets.cfg):

```
[tools_calibrate]
pin: ^PG11
travel_speed: 10#10#75
spread: 8 #8
lower_z: 0.5 #0.5 #1.0
lift_z: 2
# The speed (in mm/sec) to move tools down onto the probe
speed: 2.5 #5 #1
# The speed (in mm/sec) to retract between probes
lift_speed: 1 #4 #1
final_lift_z: 4 #6
samples: 1 #3 #3
samples_result: median # median, average
sample_retract_dist:5
samples_tolerance: 0.05 #0.5 #2 #0.02
# samples_tolerance_retries:3
# Decrease -> higher nozzle
trigger_to_bottom_z: 3 #0.5
```

Also for the loading and unloading of the tools, here are my settings in toollock (found in toolchanger.cfg):

```
[toollock]
purge_on_toolchange = False          # Here we can disable all purging. When disabled it overrides all other purge options. Defaults to true. This can be turned off by a macro for automatic probing hot tools without probing them. For example when doing TAMV or ZTATP.
init_printer_to_last_tool = True   #Initialise as it was turned off, unlock tool if none was loaded or lock if one was loaded. Defaults to True
tool_lock_gcode:
  SAVE_GCODE_STATE NAME=tool_unlock_state                                         # Save gcode state
   G91 
   G4 P2000  # Dwell for 2 seconds (2000 milliseconds)
   G1 X-14 F{printer.save_variables.variables['ktcc_dock_move_speed']|int}
   M400
   RESTORE_GCODE_STATE NAME=tool_unlock_state MOVE=0                               # Restore gcode state
  
tool_unlock_gcode:
  SAVE_GCODE_STATE NAME=tool_lock_state                                           # Save gcode state
   G91 
   G1 X14 F{printer.save_variables.variables['ktcc_dock_move_speed']|int}
   M400
  RESTORE_GCODE_STATE NAME=tool_lock_state MOVE=0                                 # Restore gcode state
```

And for my speed settings which are located in variables.cfg:

```
[Variables]
ktcc_dock_move_speed = 4000
ktcc_speed1 = 6000
ktcc_speed2 = 500
ktcc_speed3 = 2000
```

I ran the NUDGE_FIND_TOOL_OFFSETS to get the offset measurements after here are the readings:

```
read1 = "Tool offset is 0.481250,-0.368750,-0.000000"
read2 = "Tool offset is 0.485937,-0.254688,0.022500"
read3 = "Tool offset is 0.492187,-0.260938,0.007500" 
read4 = "Tool offset is 0.490625,-0.348438,-0.009375"
read5 = "Tool offset is 0.460937,-0.253125,0.034375"
read6 = "Tool offset is 0.448437,-0.340625,0.010625"
```

For the x my average is 0.4765621666666666 and %CV is 3.41%
For the y my average is -0.3044273333333333 and %CV is 16.08%
For the z my average is 0.010937500 and %CV is 130.76%

This is a bit high and so there probably needs to be more tension in the springs. 

toollock_loose

So the springs were tightened and the test was rerun. 

```
read1 = "Tool offset is -1.470312,-0.817187,0.258750"
read2 = "Tool offset is -1.468750,-0.803125,0.263750"
read3 = "Tool offset is -1.471875,-0.810937,0.185000"
```

For the x my average is -1.470312 and %CV is 0.1062%

For the y my average is -0.81041 and %CV is 0.8699%

For the z my average is 0.23583 and %CV is 18.7035%

The nudge tool works well if you use copper screws and if you want to know how accurate the loading and unloading is. However, when printing with these recommended offsets, this is wrong.

nudge_recommended_offsets

I ended up having to print a calibration tower to figure out the offsets. For this tower, I ended up having the following offsets, t1_offset = (-3.2, -0.81041, 0.23583). So its just the x offset where there is big changes. But the y offset also needs to be adjusted slightly which I still need to do. I think the y offset probably needs to be adjust to -0.61 (200 microns less) 

If you wanted to manual query the nudge tool, you can run TOOL_CALIBRATE_QUERY_PROBE. Then you can just manually test this.

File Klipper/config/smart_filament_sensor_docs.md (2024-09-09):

### smart_filament_sensors.cfg 

This works with smart filament sensor: https://www.printables.com/model/489791-smart-filament-sensor

You can define for each tool. 

<details><summary>filament_motion_sensor encoder_t0</summary>

```
[filament_motion_sensor encoder_t0]
detection_length: 10
extruder: extruder
#switch_pin: ^!PE4
switch_pin: ^!EBB0: PB5
pause_on_runout: false
runout_gcode: FILAMENT_ISRUNOUT
```

</details>

<details><summary>filament_motion_sensor encoder_t1</summary>

```
[filament_motion_sensor encoder_t1]
detection_length: 10
extruder: extruder1
#switch_pin: ^!PE4
switch_pin: ^!EBB1: PB5
pause_on_runout: false
runout_gcode: FILAMENT_ISRUNOUT
```

</details>

<details><summary>gcode_macro FILAMENT_ISRUNOUT</summary>

```
[gcode_macro FILAMENT_ISRUNOUT]
description: Is called when filament runout is detected by filament_motion_sensor
gcode:
 {% set runout_state = "delay_runout_check" if printer.print_stats.print_duration < 30 else "runout" %}
 {% set runout_state = "not_printing" if printer.idle_timeout.state != "Printing" else "runout" %}
 # {% set runout_state = "nope" if 1 == 2 else "runout" %}
 {% set counter = printer["gcode_macro cfgs"].counter + 1 %}
 SET_GCODE_VARIABLE MACRO=cfgs VARIABLE=counter VALUE='{counter}'
 # { action_respond_info("counter: %i" % (counter)) }
 { action_respond_info("runout state: %s" % (runout_state)) }
 {% if runout_state == "delay_runout_check" %} 
     { action_respond_info("No runout detection first 30 seconds of print duration.") }
 {% elif runout_state == "not_printing" %}
     ## Printer not in printing state
     { action_respond_info("No runout detection as printer is not in printing state.") }
 {% else %}
       {% set breaker = namespace(found=False) %}
       {% if runout_state == "runout" %}
           {% if counter < 4 %}
               UPDATE_DELAYED_GCODE ID=RECHECK_FILAMENT_ISRUNOUT DURATION=5 ; Recheck after XXs duration
               { action_respond_info("Detected possible runout. Recheck runout sensor in 5s.") }
           {% else %}
               SET_GCODE_VARIABLE MACRO=cfgs VARIABLE=counter VALUE='0'
               { action_respond_info("Detected actual runout. Go to filament change position.") }
               M600 ; Go To Filament Change position
              {% set breaker.found = true %}
           {% endif %} 
       {% endif %} 
 {% endif %}
```
</details>

<details><summary>delayed_gcode RECHECK_FILAMENT_ISRUNOUT</summary>

```
[delayed_gcode RECHECK_FILAMENT_ISRUNOUT]             
gcode:
    {% set rechecks = printer["gcode_macro cfgs"].rechecks %}
    {% set rechecks=rechecks+1 %}
    SET_GCODE_VARIABLE MACRO=cfgs VARIABLE=rechecks VALUE='{rechecks}'
    {% if printer["filament_motion_sensor filament_sensor"].filament_detected == True %}
        { action_respond_info("filament found, total rechecks: %i"  % (rechecks | int)) }
        SET_GCODE_VARIABLE MACRO=cfgs VARIABLE=counter VALUE='0'
    {% else %}
         { action_respond_info("no filament detected, total rechecks: %i"  % (rechecks | int)) }
        FILAMENT_ISRUNOUT
    {% endif %}
```
</details>

<details><summary>gcode_macro cfgs</summary>

```
[gcode_macro cfgs]
variable_counter: 0
variable_rechecks: 0
gcode:
      { action_respond_info("var is loaded.") } 
```
</details>

<details><summary>delayed_gcode SETFILAMENTSENSOR_ON</summary>

``` 
[delayed_gcode SETFILAMENTSENSOR_ON]
gcode:
  {% if params.T|int > 0 and params.T|int < 5 %}
 	#SET_FILAMENT_SENSOR SENSOR=filament_sensor ENABLE=1
 	SET_FILAMENT_SENSOR SENSOR=encoder_t{params.T} ENABLE=1
  {% endif %}
```
</details>

<details><summary>delayed_gcode SETFILAMENTSENSOR_OFF</summary>

``` 
[delayed_gcode SETFILAMENTSENSOR_OFF]
gcode:
  {% if params.T|int > 0 and params.T|int < 5 %}
 	#SET_FILAMENT_SENSOR SENSOR=filament_sensor ENABLE=1
 	SET_FILAMENT_SENSOR SENSOR=encoder_t{params.T} ENABLE=0
  {% endif %}
```
</details>

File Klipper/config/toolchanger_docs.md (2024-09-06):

### toolchanger.cfg 

Following includes:

```
[include klipper_toolchanger/*.cfg]
[include tools/*.cfg]
[include calibrate-offsets.cfg]      
[include crash_detection.cfg]
[include dock_calibrate.cfg]
[include status_led.cfg]
[include filament_sensors.cfg]
[include tool_usage.cfg]

# Enables saving of variables between powerdown of machine. Must be configured before [toollock].
[save_variables]
filename:  ~/printer_data/config/variables.cfg
```

<details><summary>toollock</summary>

```
[toollock]
purge_on_toolchange = False          # Here we can disable all purging. When disabled it overrides all other purge options. Defaults to true. This can be turned off by a macro for automatic probing hot tools without probing them. For example when doing TAMV or ZTATP.
init_printer_to_last_tool = True   #Initialise as it was turned off, unlock tool if none was loaded or lock if one was loaded. Defaults to True
tool_lock_gcode:
  SAVE_GCODE_STATE NAME=tool_unlock_state                                         # Save gcode state
   G91 
   #XY_HIGH_TORQUE_START
   G1 X-14 F{printer.save_variables.variables['ktcc_dock_move_speed']|int}
   G1 X2 F{printer.save_variables.variables['ktcc_dock_move_speed']|int}
   #XY_HIGH_TORQUE_STOP
   RESTORE_GCODE_STATE NAME=tool_unlock_state MOVE=0                               # Restore gcode state
  
tool_unlock_gcode:
  SAVE_GCODE_STATE NAME=tool_lock_state                                           # Save gcode state
   G91 
   G1 X12 F{printer.save_variables.variables['ktcc_dock_move_speed']|int}
   #G1 X-1 F{printer.save_variables.variables['ktcc_dock_move_speed']|int}
  RESTORE_GCODE_STATE NAME=tool_lock_state MOVE=0                                 # Restore gcode state
```

</details>

<details><summary>toolgroup 0</summary>

```
  
# Used to group several tools with similar settings.
[toolgroup 0]
is_virtual: False            # If True then must have a physical_parent declared and shares extruder, hotend and fan with the physical_parent
pickup_gcode: 
  SUB_TOOL_PICKUP_START T={myself.name}
  SUB_TOOL_PICKUP_END T={myself.name}

dropoff_gcode:
  SUB_TOOL_DROPOFF_START T={myself.name}
  SUB_TOOL_DROPOFF_END T={myself.name}

```

</details>

<details><summary>tool 0</summary>

```

##### Selectable tool. Must be configured after [toolgroup n].
[tool 0]
tool_group: 0                     # Must be used and configured before this tool
extruder: extruder
fan: partfan_t0
zone: 0,0,0
park: 0,0,0
offset:0,0,0
meltzonelength: 0 #18                 # Defaults to 0
idle_to_standby_time: 0.1          # Time in seconds from being parked to setting temperature to standby the temperature above. Use 0.1 to change imediatley to standby temperature. Defaults to 30
idle_to_powerdown_time: 1800       # Time in seconds from being parked to setting temperature to 0. Use something like 86400 to wait 24h if you want to disable. Defaults to 600
lazy_home_when_parking: 1           # (default: 0 - disabled) - When set to 1, will home unhomed XY axes if needed and will not move any axis if already homed and parked. 2 Will also home Z if not homed.
shaper_freq_y: 103
shaper_freq_x: 33
shaper_type_y: zv
shaper_type_x: mzv

```

</details>

<details><summary>tool 1</summary>

```

[tool 1]
tool_group: 0                     # Must be used and configured before this tool
extruder: extruder1
zone: 0,0,0
park: 0,0,0
offset:0,0,0
fan: partfan_t1
meltzonelength: 0 #18                 # Defaults to 0
idle_to_standby_time: 0.1          # Time in seconds from being parked to setting temperature to standby the temperature above. Use 0.1 to change imediatley to standby temperature. Defaults to 30
idle_to_powerdown_time: 1800       # Time in seconds from being parked to setting temperature to 0. Use something like 86400 to wait 24h if you want to disable. Defaults to 600
lazy_home_when_parking: 1           # (default: 0 - disabled) - When set to 1, will home unhomed XY axes if needed and will not move any axis if already homed and parked. 2 Will also home Z if not homed.
shaper_freq_y: 103
shaper_freq_x: 33
shaper_type_y: zv
shaper_type_x: mzv

```

</details>

<details><summary>SUB_TOOL_PICKUP_START</summary>

```

[gcode_macro SUB_TOOL_PICKUP_START]
description: Internal subroutine. Do not use!
# Tnnn: Tool to pickup
gcode:

  TOOLCHANGE_Z_MOVE_START

  {%set myself = printer['tool '~params.T]%}
  {% set lock_x = printer.save_variables.variables['t'~params.T~'_lock_x'] %}
  {% set lock_y = printer.save_variables.variables['t'~params.T~'_lock_y'] %}

  {% if printer["gcode_macro STORE_TOOLHEAD_POSITION"].toolhead_pos_stored|int == 0 and printer["gcode_macro STORE_TOOLHEAD_POSITION"].bypass_toolhead_position|int == 0 %}
      STORE_TOOLHEAD_POSITION X={printer.toolhead.position.x} Y={printer.toolhead.position.y}
  {% endif %}

  M568 P{myself.name} A2                                               # Put tool heater in Active mode

  SAVE_ACCELERATION                                                    # Save current acceleration value.
  M204 S12000                                                           # Set high acceleration for toolchanging
  #SAVE_POSITION
  SAVE_GCODE_STATE NAME=TOOL_PICKUP                                    # Save GCODE state. Will be restored at the end of SUB_TOOL_PICKUP_END
  G92 E0
  ##############  Move in to parking spot  ##############
  G0 X{lock_x|int} F{printer.save_variables.variables['ktcc_speed1']|int}                                # Fast Move near the pickup position for tool.
  G0 Y{lock_y|int-10} F{printer.save_variables.variables['ktcc_speed1']|int}                                           # Slow Move to the pickup position for tool.
  G0 Y{lock_y|int} F{printer.save_variables.variables['ktcc_speed3']|int}                                           # Slow Move to the pickup position for tool.
  ##############  Lock Tool  ##############
  #M400                                                                 # Wait for all moves to finish.

  ## Tool Picked - Change Display to the Tool Loaded
 #ENABLE_FILAMENT_SENSOR T={params.T}
  ##############  Wait for heater  ##############
  {% if myself.extruder|default("none")|lower !="none"  %}              # If the tool has an extruder:
    {% if printer[myself.extruder].can_extrude|default("false")|lower == 'false' and  printer[myself.extruder].target|int > 0 %}
      M118 - We wait for tool to reach temp
      M116 P{myself.name} S2                                                 # Wait for tool to reach target temperature.      
      M118 - We extrude 3mm
      TOOL_LOCK
      _PRIME_TOOL_IF_FIRST_USE T={params.T} FAN={myself.fan} FORCE=0
    {% else %}
      TOOL_LOCK
      M116 P{myself.name} S5 #experimental   
      {% if printer[myself.extruder].can_extrude|default("false")|lower == 'true' %}
         _PRIME_TOOL_IF_FIRST_USE T={params.T} FAN={myself.fan} FORCE=0
      {% endif %}
    {% endif %}
  {% endif %}                                                          # /

                                                        # Lock the tool.
 #TOOL_LOCK    

  ##############  Finnish up  ##############
  # Restore GCODE state. Was saved at thebegining of SUB_TOOL_PICKUP_START. Move fast to last location.
   RESTORE_GCODE_STATE NAME=TOOL_PICKUP

  ##############  Return to saved position  ##############
  #RESTORE_POSITION
  #TIMELAPSE_TAKE_FRAME

```

</details>

<details><summary>SUB_TOOL_PICKUP_END</summary>

```

[gcode_macro SUB_TOOL_PICKUP_END]
description: Internal subroutine. Do not use!
# Tnnn: Tool to pickup
gcode:

   {% set offset = printer.save_variables.variables['t'~params.T~'_offset'] %}
   {%set myself = printer['tool '~params.T]%}
   {% set lock_x = printer.save_variables.variables['t'~params.T~'_lock_x'] %}
   {% set lock_y = printer.save_variables.variables['t'~params.T~'_lock_y'] %}
   {%set global_offset_z =  printer["gcode_macro VARIABLES_LIST"].global_z_offset|float %}  
   {% if 't0_x_offset' not in printer.save_variables.variables %}
      {%set offset_x =  0 %}
      {%set offset_y =  0 %}
      {%set offset_z = 0 %}  
  {% else %}
      {%set offset_x =  printer.save_variables.variables['t'~params.T~'_x_offset']|float%}
      {%set offset_y =  printer.save_variables.variables['t'~params.T~'_y_offset']|float%}
      {% if params.T|int > 0 %}
        {%set offset_z =  printer.save_variables.variables['t0_z_offset']|float + printer.save_variables.variables['t'~params.T~'_z_offset']|float + global_offset_z|float %}
      {% else %}
        #{%set offset_z =  printer.save_variables.variables['t'~params.T~'_z_offset']|float %}
        APPLY_TOOL_OFFSET t0_z_offset
      {% endif %}    
  {% endif %}   
  ##############  Move out to zone  ##############
  #G0 Y{myself.zone[1]|int - 50} F{printer.save_variables.variables['ktcc_speed1']|int}
  G0 Y{lock_y|int - 120} F{printer.save_variables.variables['ktcc_speed1']|int}
  RESTORE_ACCELERATION 
  SET_GCODE_OFFSET X={offset_x|float} Y={offset_y|float} Z={offset_z|float} MOVE=1  # Set X and Y offsets, 
  SET_ACTIVE_TOOL_PROBE T={params.T}
  SET_STATUS_LED_LOCK T={params.T}
 
  G92 E0
  
  #SETFILAMENTSENSOR_ON T={params.T}
  #{% endif %}
  INCREMENT_TOOL_USE_COUNT T={params.T}
 
  #Move to the last position of toolhead before toolchange
    
  {% if printer["gcode_macro STORE_TOOLHEAD_POSITION"].toolhead_pos_stored|int == 1  and printer["gcode_macro STORE_TOOLHEAD_POSITION"].bypass_toolhead_position|int == 0 %}
     M118 Move to old toolhead position
     G1 X{printer["gcode_macro STORE_TOOLHEAD_POSITION"].toolhead_x} Y{printer["gcode_macro STORE_TOOLHEAD_POSITION"].toolhead_y} F{printer.save_variables.variables['ktcc_speed1']|int}
  {% endif %}
  CLEAR_TOOLHEAD_POSITION
  
  ;G4 P2000  ; Wait for 2 seconds
  M400
  ;VERIFY_TOOLCHANGE_DURING_PRINT DURATION=5 FORCE=0 #Delayed GCode to Verify Successful toolchange during a print 
  
  TOOLCHANGE_Z_MOVE_END
  
  M118 Setting gcode offset T{params.T}
  M118 OFFSET X: {offset[0]}
  M118 OFFSET Y: {offset[1]}
  M118 OFFSET Z: {offset[2]}
  SET_GCODE_OFFSET X={offset[0]} Y={offset[1]} Z={offset[2]}

```
</details>

<details><summary>SUB_TOOL_DROPOFF_START</summary>

```

[gcode_macro SUB_TOOL_DROPOFF_START]
description: Internal subroutine. Do not use!
# Tnnn: Tool to pickup
gcode:
  M118 setting gcode offset back to 0
  SET_GCODE_OFFSET X=0 Y=0 Z=0
  TOOLCHANGE_Z_MOVE_START
  
  {%set myself = printer['tool '~params.T]%}  
  {% set lock_x = printer.save_variables.variables['t'~params.T~'_lock_x'] %}
  {% set unlock_x = printer.save_variables.variables['t'~params.T~'_unlock_x'] %}
  {% set unlock_y = printer.save_variables.variables['t'~params.T~'_unlock_y'] %}

  ##Turn Off All Filament Sensors
  #TURN_OFF_ALL_FILAMENT_SENSORS
  
  #############  Retract the filament as per e3d Revo documentation  ##############
  {% if myself.extruder|default("none")|lower !="none" %}       # If the tool has an extruder:
    M568 P{myself.name} A1                                        # Put tool heater in standby
    SET_STEPPER_ENABLE STEPPER={ myself.extruder|lower} ENABLE=0  # turn off E Motor
  {% endif %}
  
  {% if printer["gcode_macro STORE_TOOLHEAD_POSITION"].toolhead_pos_stored|int == 0  and printer["gcode_macro STORE_TOOLHEAD_POSITION"].bypass_toolhead_position|int == 0%}  
      STORE_TOOLHEAD_POSITION X={printer.toolhead.position.x} Y={printer.toolhead.position.y}
  {% endif %} 	 

  SAVE_ACCELERATION                                            # Save current acceleration value.
  M204 S12000                                                   # Set high acceleration for toolchanging
 
  {% if myself.name|int != printer.toollock.tool_current|int %}
   { action_raise_error("SUB_TOOL_DROPOFF_START: Wrong tool. Asked to dropoff T" ~ myself.name ~ " while current is T" ~ printer.toollock.tool_current ~ ".") }
  {% endif %}

 ##############  Move in to parking spot  ##############

  SET_GCODE_OFFSET X=0 Y=0 MOVE=1                                    # Set XY offset to 0 so we park the tool right.
 
  G0 X{unlock_x|int} Y{unlock_y|int-120} F{printer.save_variables.variables['ktcc_speed1']|int}               # Fast Move near the pickup position for tool.
  G0 Y{unlock_y-30|int} F{printer.save_variables.variables['ktcc_speed1']|int} 
  G0 Y{unlock_y|int} F{printer.save_variables.variables['ktcc_speed2']|int}                                        # Slow Move to the pickup position for tool.
 
  SAVE_GCODE_STATE NAME=TOOL_DROPOFF_002                        # Save GCode state.
  G90                                                           # Absolute positions
  TOOL_UNLOCK
  G0 Y{unlock_y|int-20} F{printer.save_variables.variables['ktcc_speed2']|int}
  #G0 Y{unlock_y|int} F{printer.save_variables.variables['ktcc_speed2']|int}
  #G0 Y{unlock_y-30|int} F{printer.save_variables.variables['ktcc_speed2']|int} 
  G0 Y{unlock_y|int-80} F{printer.save_variables.variables['ktcc_speed1']|int}

  #SET_GCODE_OFFSET Z=0 MOVE=1                                     # Set XY offset to 0 so we park the tool right. 
   
  ## Tool Dropped- Change Display to No Tool Loaded
  
```
</details>

<details><summary>SUB_TOOL_DROPOFF_END</summary>

```

[gcode_macro SUB_TOOL_DROPOFF_END]
description: Internal subroutine. Do not use!
gcode:
  {%set myself = printer['tool '~params.T]%}

  SET_STATUS_LED_DOCK T={params.T}

  RESTORE_GCODE_STATE NAME=TOOL_DROPOFF_002 MOVE=0   # Restore Gcode state
  RESTORE_ACCELERATION                # Restore saved acceleration value.       

```
</details>

<details><summary>_PRIME_TOOL_IF_FIRST_USE</summary>

```

[gcode_macro _PRIME_TOOL_IF_FIRST_USE]
gcode:
  {% if printer["gcode_macro TOOL_USE_COUNT"]['t'~params.T~'_use_count'] == 0 or params.FORCE|int ==1 %}
    G91
    G92 E0
    SET_FAN_SPEED FAN={params.FAN} SPEED=1
    G1 E15 F400
    #G4 P4000
    SET_FAN_SPEED FAN={params.FAN} SPEED=0
    G92 E0
    #G1 E5 F300
    G90
  {% endif %}

```
</details>

<details><summary>PREPARE_TOOL_BEFORE_RESUME</summary>

```

[gcode_macro PREPARE_TOOL_BEFORE_RESUME]
gcode:
  {% set tool = printer["gcode_macro VARIABLES_LIST"].active_tool %}
  {% set bed_temp = printer["gcode_macro VARIABLES_LIST"].current_bed_temp %}
  {% set unlock_x = printer.save_variables.variables['t'~tool~'_unlock_x'] %}
  {% set unlock_y = printer.save_variables.variables['t'~tool~'_unlock_y'] %}

  M118 "Heating Bed to {bed_temp}"
  ; Heat the bed first
  M140 S{bed_temp}
  M190 Sbed_temp} ; wait for bed temp

  ; Wait for bed to reach temperature with 2 degrees tolerance
  M116 H0 S2 ; Wait for bed to reach temperature with 2 degrees tolerance

  M118 "Heating Hotend to temperature"
  M568 P{tool} A2

  G28 Y
  G28 X

  #Heat up the toolhead to temp if its not heated

  {% if tool == 0 %}
    {% set extruder_name="extruder" %}
  {% else %}
    {% set extruder_name="extruder"~tool %}
  {% endif %}
  #SET_GCODE_OFFSET X=0 Y=0 MOVE=1                                    # Set XY offset to 0 so we park the tool right.
  G90
  #Move to Nozzle Priming Location 
  G0 X{unlock_x|int} Y{unlock_y|int-120} F{printer.save_variables.variables['ktcc_speed1']|int}               # Fast Move near the pickup position for tool.
  G0 Y{unlock_y|int} F{printer.save_variables.variables['ktcc_speed1']|int}                                         # Slow Move to the pickup position for tool.

  M116 P{tool} S2
  #Prime Nozzle Again
  {% if printer[extruder_name].can_extrude|default("false")|lower == 'false' %}
    _PRIME_TOOL_IF_FIRST_USE T={tool} FAN=partfan_t{tool} FORCE=1
  {% endif %}

    ;SET_STATUS_LED_LOCK T={tool}
  #Move Out to the main build area 
  G0 Y{unlock_y|int-120} F{printer.save_variables.variables['ktcc_speed1']|int}
  G91

```
</details>

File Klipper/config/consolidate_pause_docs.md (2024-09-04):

This works with smart_filament_sensor.cfg: https://www.printables.com/model/489791-smart-filament-sensor

<details><summary>CONSOLIDATE_PAUSE</summary>

```
[gcode_macro CONSOLIDATE_PAUSE]
description: Pause the actual running print
#rename_existing: PAUSE_BASE
gcode:
  ##### get user parameters or use default #####
  {% set client = printer['gcode_macro _CLIENT_VARIABLE'] | default({}) %}
  {% set idle_timeout = client.idle_timeout | default(43200) %}
  {% set temp = printer[printer.toolhead.extruder].target if printer.toolhead.extruder != '' else 0 %}
  {% set restore = False if printer.toolhead.extruder == ''
              else True  if params.RESTORE | default(1) | int == 1 else False %}
  ##### end of definitions #####

  # Check if already paused
  {% if printer['pause_resume'].is_paused|int == 0 %}
    # Save current state and set variables for resuming
    SAVE_GCODE_STATE NAME=PAUSE_state
    SET_GCODE_VARIABLE MACRO=RESUME VARIABLE=zhop VALUE=5
    SET_GCODE_VARIABLE MACRO=RESUME VARIABLE=last_extruder_temp VALUE="{{'restore': restore, 'temp': temp}}"

    # Set new idle timeout
    SET_GCODE_VARIABLE MACRO=RESUME VARIABLE=restore_idle_timeout VALUE={printer.configfile.settings.idle_timeout.timeout}
    SET_IDLE_TIMEOUT TIMEOUT={idle_timeout}

    # Retract filament 
    G91
    G1 E-1 F2700
    G90

    # Perform pause actions
    PAUSE_BASE
    G91
    G1 Z5 F900
    G90

    # Handle filament sensor (if applicable)
    {% if params.T|int > 0 and params.T|int < 5 %}
      SET_FILAMENT_SENSOR SENSOR=encoder_t{params.T} ENABLE=0
    {% endif %}

    # Turn off heaters and fan (optional, commented out)
    #TURN_OFF_HEATERS
    #M106 S0 

    # Custom actions
    RSCS_off
    {client.user_pause_macro | default("")}
    _TOOLHEAD_PARK_PAUSE_CANCEL {rawparams}

    # Display appropriate message
    {% if params.ERROR|default(0)|int == 1 %}
      M117 Print paused due to sensor error
    {% else %}
      M117 Print paused manually
    {% endif %}
  {% else %}
    M118 "Print Already Paused"
  {% endif %}
```
</details>

<details><summary>CONSOLIDATE_RESUME</summary>

```
[gcode_macro CONSOLIDATE_RESUME]
description: Resume the actual running print
#rename_existing: RESUME_BASE
variable_last_extruder_temp: {'restore': False, 'temp': 0}
variable_restore_idle_timeout: 0
variable_idle_state: False
variable_zhop: 5
gcode:
  ##### get user parameters or use default #####
  {% set client = printer['gcode_macro _CLIENT_VARIABLE'] | default({}) %}
  {% set velocity = printer.configfile.settings.pause_resume.recover_velocity %}
  {% set sp_move = client.speed_move | default(velocity) %}
  {% set runout_resume = True if client.runout_sensor | default("") == ""   # no runout
                    else True if not printer[client.runout_sensor].enabled  # sensor is disabled
                    else printer[client.runout_sensor].filament_detected %} # sensor status
  {% set can_extrude = True if printer.toolhead.extruder == ''           # no extruder defined in config
                  else printer[printer.toolhead.extruder].can_extrude %} # status of active extruder
  {% set do_resume = False %}
  {% set prompt_txt = [] %}
  ##### end of definitions #####
  {% if printer.pause_resume.is_paused %}
    {% if printer["gcode_macro VARIABLES_LIST"].tc_state == 0 %}
      #### Printer coming from timeout idle state ####
      {% if printer.idle_timeout.state | upper == "IDLE" or idle_state %}
        SET_GCODE_VARIABLE MACRO=RESUME VARIABLE=idle_state VALUE=False
        {% if last_extruder_temp.restore %}
          RESPOND TYPE=echo MSG='{"Restoring \"%s\" temperature to %3.1f\u00B0C, this may take some time" % (printer.toolhead.extruder, last_extruder_temp.temp) }'
          TEMPERATURE_WAIT SENSOR=extruder minimum={last_extruder_temp.temp-2} maximum={last_extruder_temp.temp+2}
          {% set do_resume = True %}
        {% elif can_extrude %}
          {% set do_resume = True %}
        {% else %}
          RESPOND TYPE=error MSG='{"Resume aborted !!! \"%s\" not hot enough, please heat up again and press RESUME" % printer.toolhead.extruder}'
          {% set _d = prompt_txt.append("\"%s\" not hot enough, please heat up again and press RESUME" % printer.toolhead.extruder) %}
        {% endif %}
      #### Printer coming out of regular PAUSE state ####
      {% elif can_extrude %}
        {% set do_resume = True %}
      {% else %}
        RESPOND TYPE=error MSG='{"Resume aborted !!! \"%s\" not hot enough, please heat up again and press RESUME" % printer.toolhead.extruder}'
        {% set _d = prompt_txt.append("\"%s\" not hot enough, please heat up again and press RESUME" % printer.toolhead.extruder) %}
      {% endif %}

      {% if runout_resume %}
        {% if do_resume %}
          {% if restore_idle_timeout > 0 %} SET_IDLE_TIMEOUT TIMEOUT={restore_idle_timeout} {% endif %}
          {client.user_resume_macro | default("")}
          _CLIENT_EXTRUDE
          G91
          G1 Z-{zhop} F900  # Move Z back down by zhop amount
          G90
          #  Prime the nozzle
          G91
    	  G1 E1 F2700
    	  G90

          {% if printer["gcode_macro VARIABLES_LIST"]["print_status"]|int == 1 %}
            {% if printer["gcode_macro VARIABLES_LIST"]["pause_type"]|int == 1%}
              PREPARE_TOOL_BEFORE_RESUME
            {% endif %}
          {% endif %}
          RESTORE_GCODE_STATE NAME=PAUSE_state
          RESUME_BASE VELOCITY={params.VELOCITY | default(sp_move)}
          VERIFY_TOOLCHANGE_DURING_PRINT DURATION=5 FORCE=1
          SAVE_GCODE_STATE NAME=PAUSE_state
          RSCS_LAYER_CHECK LAYER={printer["gcode_macro VARIABLES_LIST"].current_layer}
          RESET_PAUSE_TYPE
          {% if printer["gcode_macro VARIABLES_LIST"].active_tool|int > -1 %}
            SET_STATUS_LED_LOCK T={printer["gcode_macro VARIABLES_LIST"].active_tool}
          {% endif %}
          SET_ENCLOSURE_DEFAULT
          UPDATE_DELAYED_GCODE ID=SETFILAMENTSENSOR_ON DURATION=5
        {% endif %}
      {% else %}
        RESPOND TYPE=error MSG='{"Resume aborted !!! \"%s\" detects no filament, please load filament and press RESUME" % (client.runout_sensor.split(" "))[1]}'
        {% set _d = prompt_txt.append("\"%s\" detects no filament, please load filament and press RESUME" % (client.runout_sensor.split(" "))[1]) %}
      {% endif %}

      ##### Generate User Information box in case of abort #####
      {% if not (runout_resume and do_resume) %}
        RESPOND TYPE=command MSG="action:prompt_begin RESUME aborted !!!"
        {% for element in prompt_txt %}
          RESPOND TYPE=command MSG='{"action:prompt_text %s" % element}'
        {% endfor %}
        RESPOND TYPE=command MSG="action:prompt_footer_button Ok|RESPOND TYPE=command MSG=action:prompt_end|info"
        RESPOND TYPE=command MSG="action:prompt_show"
      {% endif %}
    {% else %}
      M118 "Printer in Error State - Cannot Resume Print"
    {% endif %}
  {% endif %}
  RESTORE_GCODE_STATE NAME=PAUSE_state MOVE=1
  RESUME_BASE VELOCITY={params.VELOCITY | default(sp_move)}
```
</details>

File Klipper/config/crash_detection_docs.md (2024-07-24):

### crash_detection.cfg - INTELLIGENT ERROR DETECTION

Notes: 

This works when called by toolchanger.cfg. This is called in different locations:

1. [gcode_macro SUB_TOOL_PICKUP_END] calls  VERIFY_TOOLCHANGE_DURING_PRINT DURATION=30 FORCE=0
   
  DURATION=30: This sets the verification duration to 30 seconds. During this time, Klipper will monitor the tool change process to ensure it completes successfully.

  FORCE=0: This parameter controls the behavior if the tool change verification fails. A value of 0 means that if the verification fails, the print will pause and wait for manual intervention to resume. If FORCE were set to 1, the print would abort instead of pausing.

Details about script:

<details>
<summary>VARIABLES_LIST</summary>
  
```
[gcode_macro VARIABLES_LIST]
variable_tools:[0,1]
variable_active_tool:-1
variable_tc_state:0 #-1:Error, 0: Operational
variable_tc_error_code:0 # 0: No Error, 1: No Tool Attached to Carriage, 2: Tool Dock Failure, 3: Multiple Tools Attached  
variable_global_z_offset:0
variable_error_tools:[]
variable_t0_used_in_print:0
variable_t1_used_in_print:0
variable_print_status:0
variable_current_layer:0
variable_current_bed_temp:0
variable_pause_type:0 # 0: No Error, 1:ToolChanger Error 2: Filament Error

gcode:
```

</details>

<details><summary>_EVALUATE_MACHINE_STATE_QUICK</summary>
  
```
  [gcode_macro _EVALUATE_MACHINE_STATE_QUICK]
gcode:
  {% set allTools = printer["gcode_macro VARIABLES_LIST"].tools %}
  {% set activeTools = [] %}
  {% set accountedTools = [] %}

  #M118 "--->_EVALUATE_MACHINE_STATE_QUICK"
  {% for tool in allTools %}

          #We do both hall effects individually to catch the case where carriage is sitting flush with a tool while it is still in dock
          {% if printer["atc_switch tc"~tool].state == "PRESSED" %}
                  {activeTools.append(tool|int)}
                  {accountedTools.append(tool)}
          {% endif %}
          {% if printer["atc_switch td"~tool].state == "PRESSED" %}
                        {accountedTools.append(tool)}
          {% endif %}
  {% endfor %}

  #M118 Active Tools {activeTools}
  #M118 Account Tools {accountedTools}
  #M118 All Tools {allTools}

  {% if accountedTools|length !=  allTools|length or printer["gcode_macro VARIABLES_LIST"].tc_state == -1 %}
         #Error Detected
         #M118 "Tools Mismatch"     
        _EVALUATE_MACHINE_STATE
  {% else %}
        # Check if Active Tool has changed
        #M118 Active Tools {activeTools}

          {% if activeTools|length > 0 %}
                {% set active_tool = activeTools[0]|int %}
        {% else %}
                {% set active_tool = -1 %}
        {% endif %}
        #M118 "Active Tool {active_tool}"
        {% if active_tool != printer["gcode_macro VARIABLES_LIST"].active_tool %}
                 #M118 "Active Tool has Changed"            
             _EVALUATE_MACHINE_STATE
        {% endif %}
  {% endif %}
```

</details>

<details><summary>_EVALUATE_MACHINE_STATE</summary>

```
[gcode_macro _EVALUATE_MACHINE_STATE]
gcode:

  {% set allTools = printer["gcode_macro VARIABLES_LIST"].tools %}
  {% set activeTools = [] %}
  {% set dockedTools = [] %}
  {% set accountedTools = [] %}
  {% set errorTools = [] %}

  {% for tool in allTools %}
        #Find All Tools attached to the carriage - should be only 1
        {% if printer["atc_switch tc"~tool].state == "PRESSED" %}
                {activeTools.append(tool|int)}
                {accountedTools.append(tool|int)}
        {% endif %}

        #Find All Tools attached to the docks - should be maximum num tools               
        {% if printer["atc_switch td"~tool].state == "PRESSED" %}
                {dockedTools.append(tool|int)}
                {accountedTools.append(tool|int)}
        {% endif %}
  {% endfor %}

  #Ensure each tool only shows up either in active or docked list - if not, throw error with the specific tool

  #M118 Active Tools {activeTools}
  #M118 Docked Tools {dockedTools}

  {% if (activeTools|length|int <= 1) and (activeTools|length + dockedTools|length ==  allTools|length ) %}

                #All Is Well- all tools are accounted for 
                M118 "All Tools Accounted For - Proceeding with Normal Startup"
                {% if activeTools|length > 0 %}
                        SET_GCODE_VARIABLE MACRO=VARIABLES_LIST VARIABLE=active_tool VALUE={activeTools[0]}
                {% else %}
                        SET_GCODE_VARIABLE MACRO=VARIABLES_LIST VARIABLE=active_tool VALUE=-1 #No Tool Attached
                {% endif %}

                SET_GCODE_VARIABLE MACRO=VARIABLES_LIST VARIABLE=tc_state VALUE=0
                SET_GCODE_VARIABLE MACRO=VARIABLES_LIST VARIABLE=tc_error_code VALUE=0

  {% else %}
                #Check if multiple tools are showing up as attached to carriage - could be an issue with the carriage attach hall effect sensor on a docked tool returning a success
                  {% if (activeTools|length == 0) and (dockedTools|length <  allTools|length ) %}

                        # A Tool should be attached to the carriage but isnt - maybe it has fallen off during printing
                        M118 " A Tool should be attached to the carriage but No Tool is present"

                        {% set allToolsTemp = allTools %}
                        {% for tool in accountedTools %}
                                {allToolsTemp.pop(allToolsTemp.index(tool))}
                        {% endfor %}

                        {% for tool in allToolsTemp %}
                                {errorTools.append(tool)}
                        {% endfor %}

                        SET_GCODE_VARIABLE MACRO=VARIABLES_LIST VARIABLE=tc_state VALUE=-1
                        SET_GCODE_VARIABLE MACRO=VARIABLES_LIST VARIABLE=tc_error_code VALUE=1

                  {% else %}
                        {% if activeTools|length > 1 %}

                                {% set allToolsTemp = allTools %}
                                M118 "Multiple Tools Showing up as attached to carriage"

                                {% for tool in activeTools %}
                                        {% if printer["atc_switch tc"~tool].state == "PRESSED" and printer["atc_switch td"~tool].state == "PRESSED" %}
                                                {errorTools.append(tool)}
                                        {% endif %}
                                {% endfor %}

                                SET_GCODE_VARIABLE MACRO=VARIABLES_LIST VARIABLE=tc_state VALUE=-1
                                SET_GCODE_VARIABLE MACRO=VARIABLES_LIST VARIABLE=tc_error_code VALUE=3

                        {% else %}
                                # Check if any tools shows up in both active and docked lists - possible if the carriage is sitting flush with a tool while it is still in dock
{% if activeTools|length + dockedTools|length > allTools|length and printer["gcode_macro VARIABLES_LIST"]["print_status"]|int != 1 %}
                                        M118 "Error: Tools are showing up in both active and docked list"
                                        {% set dockedToolsTemp = dockedTools %}

                                        {% for tool in activeTools %}
                                                        {errorTools.append(dockedToolsTemp.pop(dockedToolsTemp.index(tool)))}
                                        {% endfor %}
                                        SET_GCODE_VARIABLE MACRO=VARIABLES_LIST VARIABLE=tc_state VALUE=-1
                                        SET_GCODE_VARIABLE MACRO=VARIABLES_LIST VARIABLE=tc_error_code VALUE=4   
                                        {% else %}
                                                #Check if any of the tools supposed to be docked is not properly seated in the dock
                                                {% if dockedTools|length !=  allTools|length - 1 %}

                                                                M118 "Mismatch in number of tools docked"

                                                                {% set allToolsTemp = allTools %}
                                                                {% for tool in accountedTools %}
                                                                        {allToolsTemp.pop(allToolsTemp.index(tool))}
                                                                {% endfor %}

                                                                {% for tool in allToolsTemp %}
                                                                        {errorTools.append(tool)}
                                                                {% endfor %}

                                                                SET_GCODE_VARIABLE MACRO=VARIABLES_LIST VARIABLE=tc_state VALUE=-1
                                                                SET_GCODE_VARIABLE MACRO=VARIABLES_LIST VARIABLE=tc_error_code VALUE=2

                                                {% endif %}
                                        {% endif %}
                        {% endif %}
                {% endif %}
  {% endif %}

  {% if errorTools|length > 0 %}
        # Error Tools Found  - set the LEDS on error tools and enclosure to the ERROR state
        M118 "Error Tools: " {errorTools}
        {% for tool in errorTools %}
           #Blink STATUS LEDS on the Error Tools
                SET_STATUS_LED_ERROR_START T={tool}
        {% endfor %}
        SET_ENCLOSURE_ERROR_START
        PAUSE_AND_ALERT
  {% else %}

          # All Checked out - set the LEDS on all tools and enclosure to the default ALL OK state
          {% if activeTools|length > 0 %}
                {% for tool in activeTools %}
                        #M118 "Set Active Tool {tool}"
                        ;SET_STATUS_LED_LOCK T={tool}
                        _SET_CURRENT_TOOL T={tool}
                {% endfor %}
          {% else %}
                         # M118 "Set Active Tool {tool}"
                        _SET_CURRENT_TOOL T=-1
          {% endif %}

          {% for tool in dockedTools %}
                {% if printer["gcode_macro VARIABLES_LIST"]["print_status"]|int == 1%}
                        {% if printer["gcode_macro VARIABLES_LIST"]["t"~tool~"_used_in_print"]|int == 1%}
                                SET_STATUS_LED_DOCK T={tool}
                        {% else %}
                                SET_STATUS_LED_NOT_IN_USE T={tool}
                        {% endif %}
                {% else %}
                                SET_STATUS_LED_DOCK T={tool}                    
                {% endif %}
          {% endfor %}

          ;SET_ENCLOSURE_DEFAULT  

  {% endif %}

```
  
</details>

<details><summary>_SET_CURRENT_TOOL</summary>

```
[gcode_macro _SET_CURRENT_TOOL]
gcode:
        SAVE_CURRENT_TOOL T={params.T}
        {% if params.T|int > -1 %}
                ;SET_ACTIVE_TOOL_PROBE T={params.T}
                {% if params.T|int > 0 %}
                        ACTIVATE_EXTRUDER EXTRUDER=extruder{params.T}
                {% else %}
                        ACTIVATE_EXTRUDER EXTRUDER=extruder
                {% endif %}
                {% if 't0_x_offset' not in printer.save_variables.variables %}
                        {%set offset_x =  0 %}
                        {%set offset_y =  0 %}
                        {%set offset_z = 0 %}
                {% else %}
                        {% set offset_x =  printer.save_variables.variables['t'~params.T~'_x_offset']|float%}
                        {% set offset_y =  printer.save_variables.variables['t'~params.T~'_y_offset']|float%}
                        {% if params.T|int > 0 %}
                                {%set offset_z =  printer.save_variables.variables['t0_z_offset']|float + printer.save_variables.variables['t'~params.T~'_z_offset']|float%}
                        {% else %}
                                {%set offset_z =  printer.save_variables.variables['t'~params.T~'_z_offset']|float %}
                        {% endif %}
                {% endif %}
                #M118 T{params.T}
                #M118 OFFSET X: {offset_x}
                #M118 OFFSET Y: {offset_y}
                #M118 OFFSET Z: {offset_z}

                {% if printer.toolhead.homed_axes !="xyz" %}
                        SET_KINEMATIC_POSITION X=160 Y=160 Z=100
                {% endif %}

                SET_GCODE_OFFSET X={offset_x|float} Y={offset_y|float} Z={offset_z|float} MOVE=1

        {% endif %}

```
  
</details>

#### Tool Management For Current Print

<details><summary>GET_TOOLS_FOR_PRINT</summary>

```
[gcode_macro GET_TOOLS_FOR_PRINT]
gcode:
        {% set allTools = printer["gcode_macro VARIABLES_LIST"].tools %}
        {% set toolsforprint= [] %}
        {% for tool in allTools %}
                {% if printer["gcode_macro VARIABLES_LIST"]["t"~tool~"_used_in_print"]|int == 1%}
                        {toolsforprint.append(tool)}
                {% endif %}
        {% endfor %}
        #M118 Tools Used In Current Print: {toolsforprint}
```

</details>

<details><summary>RESET_TOOLS_FOR_PRINT</summary>

```
[gcode_macro RESET_TOOLS_FOR_PRINT]
gcode:
  {% set allTools = printer["gcode_macro VARIABLES_LIST"].tools %}
  {% for tool in allTools %}
          SET_GCODE_VARIABLE MACRO=VARIABLES_LIST VARIABLE=t{tool}_used_in_print VALUE=0
  {% endfor %}
```

</details>

<details><summary>SET_TOOL_FOR_PRINT</summary>

```
[gcode_macro SET_TOOL_FOR_PRINT]
gcode:
        SET_GCODE_VARIABLE MACRO=VARIABLES_LIST VARIABLE=t{params.T}_used_in_print VALUE=1
        {% if params.R is defined and params.S is defined%}
                M568 P{params.T} R{params.R} S{params.S} A0
        {% endif %}
```
  
</details>

<details><summary>SET_PRINT_STATUS_START</summary>

```
[gcode_macro SET_PRINT_STATUS_START]
gcode:
        SET_GCODE_VARIABLE MACRO=VARIABLES_LIST VARIABLE=print_status VALUE=1

``` 

</details>

<details><summary>RESET_PRINT_STATUS</summary>

```
[gcode_macro RESET_PRINT_STATUS]
gcode:
        SET_GCODE_VARIABLE MACRO=VARIABLES_LIST VARIABLE=print_status VALUE=0
        SET_GCODE_VARIABLE MACRO=VARIABLES_LIST VARIABLE=current_layer VALUE=0
        SET_GCODE_VARIABLE MACRO=VARIABLES_LIST VARIABLE=current_bed_temp VALUE=0
```

</details>

<details><summary>SET_CURRENT_PRINT_LAYER</summary>

```  
[gcode_macro SET_CURRENT_PRINT_LAYER]
        gcode:
                #M118 LAYER: {params.LAYER}
                #M118 BEDTEMP: {params.BEDTEMP}

                SET_GCODE_VARIABLE MACRO=VARIABLES_LIST VARIABLE=current_layer VALUE={params.LAYER}
                SET_GCODE_VARIABLE MACRO=VARIABLES_LIST VARIABLE=current_bed_temp VALUE={params.BEDTEMP}
```

</details>
  
#### MACHINE INITIALISATION

<details><summary>_INITIALIZE_ALL_TOOLS</summary>

```
[gcode_macro _INITIALIZE_ALL_TOOLS]
gcode:
  {% set allTools = printer["gcode_macro VARIABLES_LIST"].tools %}

        #TOOL LEDS INITIALIZATION
   {% for tool in allTools %}
         SET_STATUS_LED_NOT_IN_USE T={tool}
   {% endfor %}
```

</details>

#### FILAMENT SENSOR INITIALIZATION (seems empty)

#### HALL EFFECT SENSOR INITIALIZATION (seems empty)

<details><summary>RESET_DELAY_AND_CHECK_MACHINE_STATUS</summary>

```
[gcode_macro RESET_DELAY_AND_CHECK_MACHINE_STATUS]
gcode:
        {% if printer.idle_timeout.state != "Printing" %}
                #M118 "RESET_DELAY_AND_CHECK_MACHINE_STATUS"
                UPDATE_DELAYED_GCODE ID=_DELAYED_CHECK_MACHINE_STATE_QUICK DURATION=0
                UPDATE_DELAYED_GCODE ID=_DELAYED_CHECK_MACHINE_STATE_QUICK DURATION=3
        {% endif %}
```

</details>

<details><summary>VERIFY_TOOLCHANGE_DURING_PRINT</summary>

```
[gcode_macro VERIFY_TOOLCHANGE_DURING_PRINT]
        gcode:
                #M118 "VERIFY_TOOLCHANGE_DURING_PRINT in {params.DURATION} seconds with printer state: {printer.idle_timeout.state} FORCE: {params.FORCE}"
                {% if printer.idle_timeout.state == "Printing" or params.FORCE|int == 1 %}
                        #M118 "EXECUTING VERIFY_TOOLCHANGE_DURING_PRINT in {params.DURATION} seconds"
                        UPDATE_DELAYED_GCODE ID=_DELAYED_CHECK_MACHINE_STATE_QUICK DURATION=0
                        UPDATE_DELAYED_GCODE ID=_DELAYED_CHECK_MACHINE_STATE_QUICK DURATION={params.DURATION}
                {% endif %}
```

</details>

<details><summary>_DELAYED_CHECK_MACHINE_STATE_QUICK</summary>

```
[delayed_gcode _DELAYED_CHECK_MACHINE_STATE_QUICK]
initial_duration: 0
gcode:
        #M118 "Evaluating Machine State"
        _EVALUATE_MACHINE_STATE_QUICK
        {% if printer.idle_timeout.state == "Printing" %}
                VERIFY_TOOLCHANGE_DURING_PRINT DURATION=5 FORCE=0
        {% endif %}
```

</details>

<details><summary>RESET_TOOLCHANGER</summary>

```
[gcode_macro RESET_TOOLCHANGER]
gcode:
        RESET_PRINT_STATUS
        RESET_TOOLS_FOR_PRINT
        _INITIALIZE_ALL_TOOLS
        _EVALUATE_MACHINE_STATE

```
</details>

<details><summary>INITIALIZE_TOOLCHANGER</summary>

```
[delayed_gcode INITIALIZE_TOOLCHANGER]
initial_duration: 1
gcode:
        RESET_TOOLCHANGER
```

</details>

<details><summary>PAUSE_AND_ALERT</summary>

```
[gcode_macro PAUSE_AND_ALERT]
gcode:
        SET_PAUSE_TYPE TYPE=1 # Set Pause Type to Toolchanger State Error
        PAUSE
        #SEND_SLACK_MESSAGE MSG="FILAMENT ERROR DETECTED - PRINT PAUSED - PLEASE CHECK. T={params.T}}"
```

</details>

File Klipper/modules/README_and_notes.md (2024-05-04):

Attributions and my notes about installing this. 

* Klipper Toolchanger - https://github.com/TypQxQ/Klipper_ToolChanger

While it is originally from this source, the code has been modified, more details are needed to explain how or it needs another dedicated repo. 
  
* Tool Probe & Rounded Path - https://github.com/viesturz/klipper-toolchanger/
* Nozzle Align - https://github.com/viesturz/NozzleAlign
* ATC Switch - https://github.com/ben5459/Klipper_ToolChanger
* LED Effects - https://github.com/julianschill/klipper-led_effect

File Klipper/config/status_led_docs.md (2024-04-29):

### LED CONFIGS

<details><summary>t0_dock_state</summary>

```  
[led_effect t0_dock_state]
   autostart:              false
   frame_rate:             24
   leds:
       neopixel:t0_led
   layers:
     static  10 1 top (0.5,0.5,0.5)
```
</details>

<details><summary>t0_lock_state</summary>

```  
[led_effect t0_lock_state]
     autostart:              false
     frame_rate:             24
     leds:
         neopixel:t0_led
     layers:
       static  10 1 top (0,0.5,0)

```
</details>

<details><summary>t1_dock_state</summary>

```  
[led_effect t1_dock_state]
    autostart:              false
    frame_rate:             24
    leds:
        neopixel:t1_led
    layers:
      static  10 1 top (0.5,0.5,0.5)
```
</details>

<details><summary>t1_lock_state</summary>

```
[led_effect t1_lock_state]
   autostart:              false
   frame_rate:             24
   leds:
       neopixel:t1_led
   layers:
     static  10 1 top (0,0.5,0)
```
</details>

<details><summary>led_effect t0_error_blink</summary>

```      
[led_effect t0_error_blink]
   autostart:              false
   frame_rate:             24
   leds:
       neopixel:t0_led
   layers:
      strobe 1 2 add (1.0,0,0)
```

</details>

<details><summary>led_effect t1_error_blink</summary>

```      
[led_effect t1_error_blink]
   autostart:              false
   frame_rate:             24
   leds:
      neopixel:t1_led
   layers:
      strobe 1 2 add (1.0,0,0)
```
</details>

<details><summary>led_effect t0_heating</summary>

```
[led_effect t0_heating]
   autostart:              false
   frame_rate:             24
   leds:
       neopixel:t0_led
   layers:
       breathing  3 0 screen (0.5,0.6,0.05)
```
</details>

<details><summary>led_effect t1_heating</summary>

```
      
[led_effect t1_heating]
   autostart:              false
   frame_rate:             24
   leds:
      neopixel:t1_led
   layers:
      breathing  3 0 screen (0.5,0.6,0.05)

```
</details>

<details><summary>led_effect t0_idle</summary>

```

[led_effect t0_idle]
   autostart:              false
   frame_rate:             24
   leds:
       neopixel:t0_led
   layers:
      static  10 1 top (0,1,0.7) 
      #static  10 1 top (0.5,0.5,0.5)

```
</details>

<details><summary>led_effect t1_idle</summary>

```

[led_effect t1_idle]
   autostart:              false
   frame_rate:             24
   leds:
      neopixel:t1_led
   layers:
      static  10 1 top (0,1,0.7) 

```
</details>

### LED MACROS

<details><summary>LED_ALL_EFFECT_STOP</summary>

```

[gcode_macro LED_ALL_EFFECT_STOP]
gcode:

   SET_LED_EFFECT EFFECT=t{params.T}_lock_state STOP=1
   SET_LED_EFFECT EFFECT=t{params.T}_error_blink  STOP=1
   SET_LED_EFFECT EFFECT=t{params.T}_dock_state STOP=1
   SET_LED_EFFECT EFFECT=t{params.T}_heating STOP=1
   SET_LED_EFFECT EFFECT=t{params.T}_idle STOP=1

```
</details>

<details><summary>SET_STATUS_LED_NOT_IN_USE</summary>

```

[gcode_macro SET_STATUS_LED_NOT_IN_USE]
   gcode:
     LED_ALL_EFFECT_STOP T={params.T}

```
</details>

<details><summary>SET_STATUS_LED_HEATING</summary>

```
   
[gcode_macro SET_STATUS_LED_HEATING]
gcode:
  LED_ALL_EFFECT_STOP T={params.T}
  SET_LED_EFFECT EFFECT=t{params.T}_heating

```
</details>

<details><summary>SET_STATUS_LED_IDLE</summary>

```

[gcode_macro SET_STATUS_LED_IDLE]
gcode:
 LED_ALL_EFFECT_STOP T={params.T}
 SET_LED_EFFECT EFFECT=t{params.T}_idle
       
```
</details>

<details><summary>SET_STATUS_LED_LOCK</summary>

```
        
[gcode_macro SET_STATUS_LED_LOCK]
gcode:
   LED_ALL_EFFECT_STOP T={params.T}
   SET_LED_EFFECT EFFECT=t{params.T}_lock_state  

```
</details>

<details><summary>SET_STATUS_LED_DOCK</summary>

```

[gcode_macro SET_STATUS_LED_DOCK]
gcode:
  LED_ALL_EFFECT_STOP T={params.T}
  {% if printer["gcode_macro VARIABLES_LIST"]["print_status"]|int < 1 %}
     SET_LED_EFFECT EFFECT=t{params.T}_dock_state 
  {% else %}
      SET_STATUS_LED_IDLE T={params.T}
  {% endif %}
  
```
</details>

<details><summary>SET_STATUS_LED_ERROR_START</summary>

```
  
[gcode_macro SET_STATUS_LED_ERROR_START]
gcode:
   LED_ALL_EFFECT_STOP T={params.T}
   SET_LED_EFFECT EFFECT=t{params.T}_error_blink  

```
</details>

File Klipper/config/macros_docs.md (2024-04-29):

#####################################################################
## Macros
#####################################################################

<details><summary>G32</summary>

``` 
[gcode_macro G32]
gcode:
    BED_MESH_CLEAR
    G28
    Z_TILT_ADJUST
    G28
    G0 X175 Y175 Z20 F6000
```
</details>

<details><summary>PRIME_LINE</summary>

``` 
# prime the nozzle 
[gcode_macro PRIME_LINE]
gcode: 
    #M117 Priming Line
    {% if "z" not in printer.toolhead.homed_axes %} ; G28 Home if needed
        G28             ; home
    {% endif %}
    SAVE_GCODE_STATE NAME=PRIME_LINE_state
    G90                                 ; absolute positioning
    G92 E0                              ; reset extruder
    G1 E10 F1000
    G1 Z5.0 F3000                       ; move Z Axis up
    G1 X10 Y50 Z0.2 F5000.0            ; move to start position
    G1 X10 Y175 Z0.2 F1000.0 E15     ; draw the first line
    G1 X10.4 Y175 Z0.2 F5000.0         ; move to side a little
    G1 X10.4 Y50 Z0.2 F1000.0 E30        ; draw the second line
    G92 E0                              ; reset Extruder
    G1 Z5.0 F3000                       ; move Z Axis up
    G1 X40 Y50 F2000.0 
    RESTORE_GCODE_STATE NAME=PRIME_LINE_state   
```
</details>

<details><summary>PRINT_START</summary>

``` 
[gcode_macro PRINT_START]
#   Use PRINT_START for the slicer starting script - please customise for your slicer of choice
gcode:    
    {% if params.BED %}
        M140 S{params.BED}         ; set bed final temp
        M190 S{params.BED}         ; wait for bed final temp
    {% endif %}
   {% if params.EXTRUDER %}
        M104 S{params.EXTRUDER}    ; set extruder final temp
        M109 S{params.EXTRUDER}    ; wait for extruder final temp
    {% endif %}
    G32
    G90             ; absolute positioning
    M82             ; absolute extruder mode
    M107            ; turn fan off
    BEDMESHLOAD
    PRIME_LINE
```
</details>

<details><summary>PRINT_END</summary>

``` 
[gcode_macro PRINT_END]
#   Use PRINT_END for the slicer ending script - please customise for your slicer of choice
gcode:

    ; Custom gcode to run at end of print
	M104 S0 		; turn off temperature
	G10 P0 R0 S0 A0	; Don't heat the tools yet. (Using G10 so SuperSlicer and PrusaSlicer recognizes we set a tool temperature)
	G10 P1 R0 S0 A0	; Don't heat the tools yet
	M140 S0 		; turn off bed
	G91 		; relative moves
	G0 Z20  		; move bed down another 30mm
	G90 		; absolute moves
    G92 E0                              ; reset extruder
	G0 X150 Y10 F30000	; Move toolhead out of the way
	SAVE_POSITION
	RSCS_OFF
    #AIR_FILTER_STOP
    BED_MESH_CLEAR

```
</details>

<details><summary>NOZZLE_CLEAN</summary>

``` 
[gcode_macro NOZZLE_CLEAN]
gcode:
   # G0 E1 F500
```
</details>

<details><summary>NOZZLE_CLEAN1</summary>

``` 
[gcode_macro NOZZLE_CLEAN1]
gcode:
    SAVE_GCODE_STATE NAME=BEFORE_CLEAN
    G91
    G0 X10 F12000       ; move to nozzle brush
    G0 Y50 F12000       ; move to nozzle brush
    G0 X-20 F12000       ; move to nozzle brush
    G0 Y-50 F12000       ; move to nozzle brush
    G0 X20 F12000       ; move to nozzle brush
    G0 Y50 F12000       ; move to nozzle brush
    G0 X-20 F12000       ; move to nozzle brush
    G0 Y-50 F12000       ; move to nozzle brush
    G0 X20 F12000       ; move to nozzle brush
    G0 Y50 F12000       ; move to nozzle brush
    G0 X-10 F12000       ; move to nozzle brush
    G0 Y-50 F12000       ; move to nozzle brush
    G90   
    RESTORE_GCODE_STATE NAME=BEFORE_CLEAN

```
</details>

<details><summary>PURGE</summary>

```
[gcode_macro PURGE]
gcode:
    SAVE_GCODE_STATE NAME=PURGE_state
    G91                 ; relative positioning
    {% for i in range(2) %}
        G1 E10 F500      ; extrude a little more
    {% endfor %}
    RESTORE_GCODE_STATE name=PURGE_state
```
</details>

<details><summary>BEDMESHPROCEDURE</summary>

``` 
[gcode_macro BEDMESHPROCEDURE]
gcode:
	BED_MESH_CLEAR
    G32
    BED_MESH_CALIBRATE
    BED_MESH_PROFILE SAVE={printer.heater_bed.target}C
    SAVE_CONFIG
```
</details>

<details><summary>BEDMESHLOAD</summary>

``` 
[gcode_macro BEDMESHLOAD]
gcode:
    
    BED_MESH_PROFILE LOAD={printer.heater_bed.target}C
```
</details>

<details><summary>TEMPADJUSTPA</summary>

``` 
[gcode_macro TEMPADJUSTPA]
gcode:
    #ABS
    {% if printer.heater_bed.target >= 100 %}
        SET_PRESSURE_ADVANCE ADVANCE=0.0435
    {% endif %}
    #PETG
    {% if printer.heater_bed.target > 80 and printer.heater_bed.target < 100 %}
        SET_PRESSURE_ADVANCE ADVANCE=0.05
    {% endif %}
    #PLA
    {% if printer.heater_bed.target <= 80 and printer.heater_bed.target > 60 %}
        SET_PRESSURE_ADVANCE ADVANCE=0.06
    {% endif %}
    {% if printer.heater_bed.target <= 60 %}
        SET_PRESSURE_ADVANCE ADVANCE=0.0
    {% endif %}
```
</details>

<details><summary>TEMPADJUSTOFFSET</summary>

``` 
[gcode_macro TEMPADJUSTOFFSET]
gcode:
    #ABS
    {% if printer.heater_bed.target >= 100 %}
        SET_GCODE_OFFSET Z=0 MOVE=1
        SET_GCODE_OFFSET Z_ADJUST=0.0 MOVE=1
    {% endif %}
    #PETG
    {% if printer.heater_bed.target > 80 and printer.heater_bed.target < 100 %}
        SET_GCODE_OFFSET Z=0 MOVE=1
        SET_GCODE_OFFSET Z_ADJUST=-0.0 MOVE=1
    {% endif %}
    #PLA
     {% if printer.heater_bed.target <= 80 and printer.heater_bed.target > 60 %}
        SET_GCODE_OFFSET Z=0 MOVE=1
        SET_GCODE_OFFSET Z_ADJUST=0.02 MOVE=1
    {% endif %}
```
</details>   

<details><summary>ZTA</summary>

``` 
[gcode_macro ZTA]
gcode:
    Z_TILT_ADJUST
```
</details>

<details><summary>CANCEL_PRINT</summary>

``` 
[gcode_macro CANCEL_PRINT]
rename_existing: BASE_CANCEL_PRINT
gcode:
    TURN_OFF_HEATERS
    
    CLEAR_PAUSE
    SDCARD_RESET_FILE
    BASE_CANCEL_PRINT
    RESET_PRINT_STATUS
    #SET_FAN_SPEED FAN=driver_fan SPEED=0
    M106 S0
    PRINT_END
    RESET_TOOLCHANGER
```
</details>

<details><summary>M600</summary>

```	
[gcode_macro M600]
    gcode:
     PAUSE
```
</details>

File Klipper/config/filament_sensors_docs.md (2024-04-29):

### filament_sensors.cfg 

This works with TCRT50000 Infrared reflective sensors. This example shows a set up for 2 tools

<details><summary>filament_motion_sensor encoder_t0</summary>

```
[filament_motion_sensor encoder_t0]
switch_pin: EBB0:PB6
detection_length: 10
extruder: extruder
pause_on_runout: True
insert_gcode:
runout_gcode:
 PAUSE_AND_ALERT_FILAMENT T=0 STATE=JAM
```

</details>

<details><summary>filament_motion_sensor encoder_t1</summary>

```
[filament_motion_sensor encoder_t1]
switch_pin: EBB1:PB5
detection_length: 10
extruder: extruder1
pause_on_runout: True
insert_gcode:
runout_gcode:
 PAUSE_AND_ALERT_FILAMENT T=1 STATE=JAM
```

</details>

<details><summary>TURN_ON_ALL_FILAMENT_SENSORS</summary>

```
[gcode_macro TURN_ON_ALL_FILAMENT_SENSORS]
gcode:
        SET_FILAMENT_SENSOR SENSOR=encoder_t0 ENABLE=1
        SET_FILAMENT_SENSOR SENSOR=encoder_t1 ENABLE=1
        M118 ENABLE ALL FILAMENT_SENSORS
```
</details>

<details><summary>TURN_OFF_ALL_FILAMENT_SENSORS</summary>

```                
[gcode_macro TURN_OFF_ALL_FILAMENT_SENSORS]
gcode:
        SET_FILAMENT_SENSOR SENSOR=encoder_t0 ENABLE=0
        SET_FILAMENT_SENSOR SENSOR=encoder_t1 ENABLE=0
        M118 DISABLE ALL FILAMENT_SENSORS
```
</details>

<details><summary>ENABLE_FILAMENT_SENSOR</summary>

```
[gcode_macro ENABLE_FILAMENT_SENSOR]
gcode:
  {% if params.T|int > 0 and params.T|int < 5 %}
         SET_FILAMENT_SENSOR SENSOR=runout_t{params.T} ENABLE=1
         SET_FILAMENT_SENSOR SENSOR=encoder_t{params.T} ENABLE=1
         M118 ENABLE FILAMENT SENSOR T{params.T}
  {% endif %}
```
</details>

<details><summary>PAUSE_AND_ALERT_FILAMENT</summary>

``` 
[gcode_macro PAUSE_AND_ALERT_FILAMENT]
gcode:
        M117 TOOLHEAD T{params.T} {params.STATE}
        SET_PAUSE_TYPE TYPE=2 # Set Pause Type to Filament
        SET_STATUS_LED_ERROR_START T={params.T}
        SET_ENCLOSURE_ERROR_START
        PAUSE
        #SEND_SLACK_MESSAGE MSG="FILAMENT ERROR DETECTED - PRINT PAUSED - PLEASE CHECK. T={params.T}}"
```
</details>

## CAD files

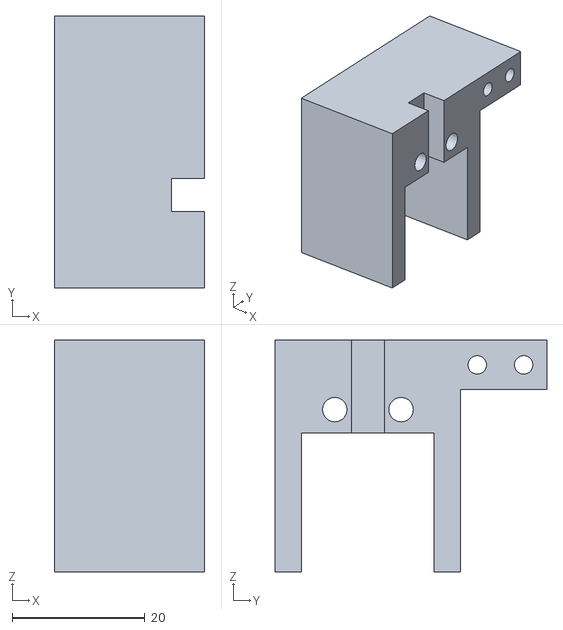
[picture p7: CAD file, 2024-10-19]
Toolhead/MG995_Servo_Linear_Actuator/servo_linear_assy_servo_holder_top.stl
22.7 x 41.0 x 35.0

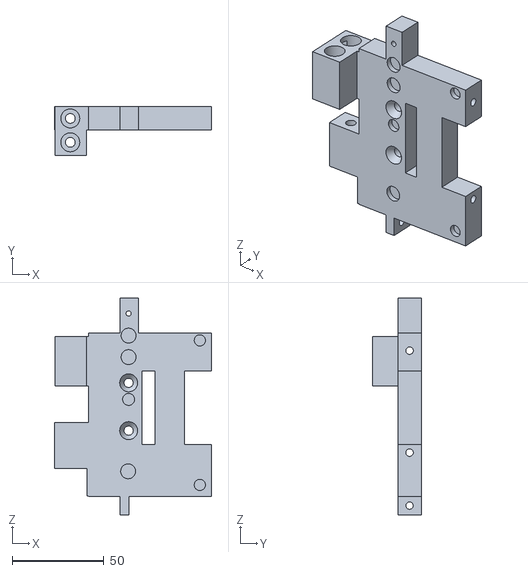
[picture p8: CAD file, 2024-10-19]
Dock/dock_main_mod_openscad_servo_linearactuator.stl
85.6 x 26.7 x 118.0

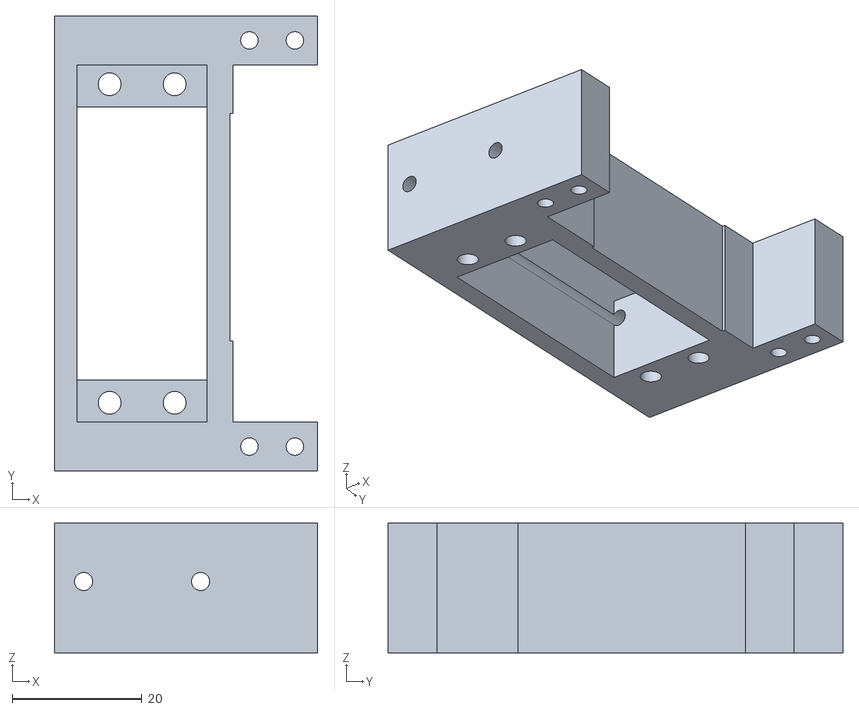
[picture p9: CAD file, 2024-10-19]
Toolhead/servo_linear_assy_servo_holder.stl
40.5 x 70.0 x 20.0

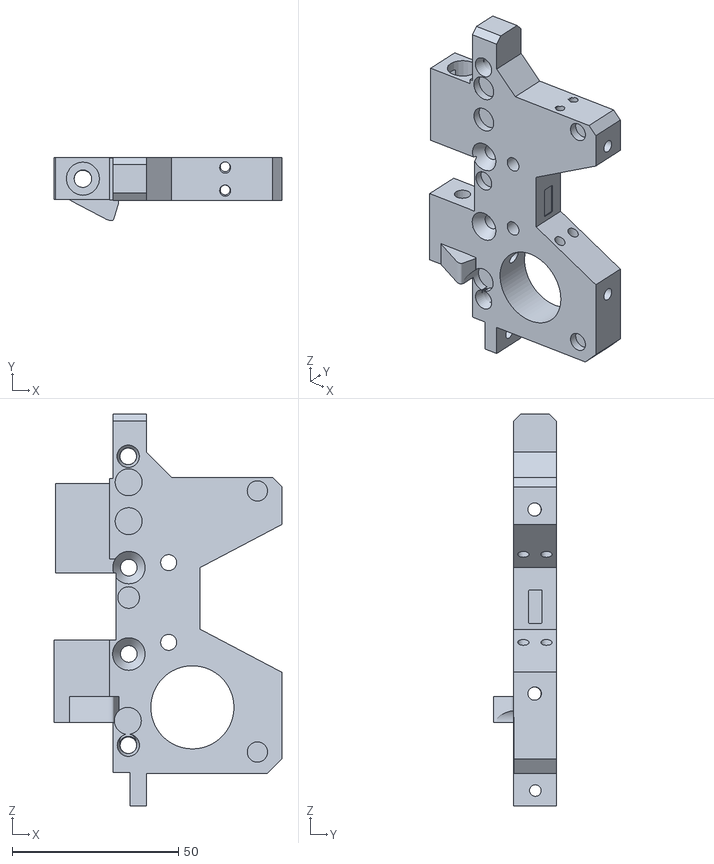
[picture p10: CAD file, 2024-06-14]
Dock/Dock_main_exp_2in1.stl
68.5 x 19.0 x 118.0

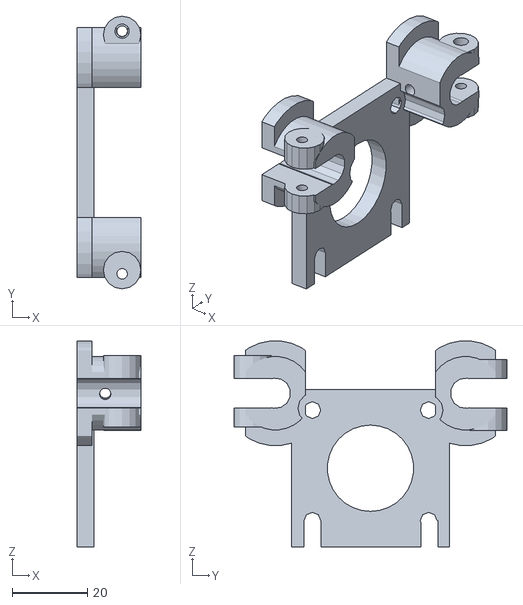
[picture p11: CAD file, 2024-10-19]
Toolhead/MG995_Servo_Linear_Actuator/files/nema17motormount_assy.stl
17.0 x 72.7 x 54.9

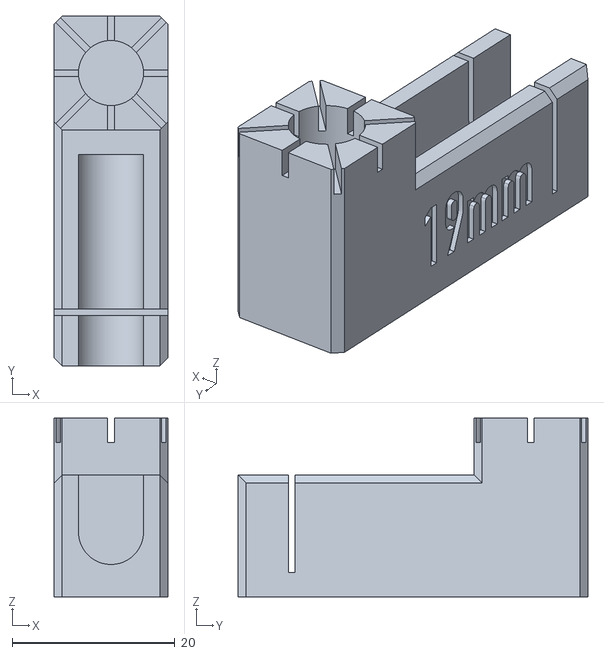
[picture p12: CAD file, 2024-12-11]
Dock/silicone_tube_cutter_v5.stl
14.0 x 43.0 x 22.0

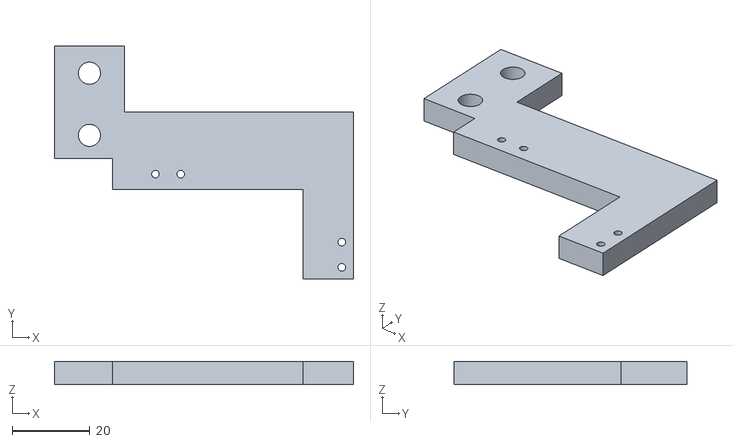
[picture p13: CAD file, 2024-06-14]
Endstop/xyendstop.stl
77.0 x 60.0 x 6.00

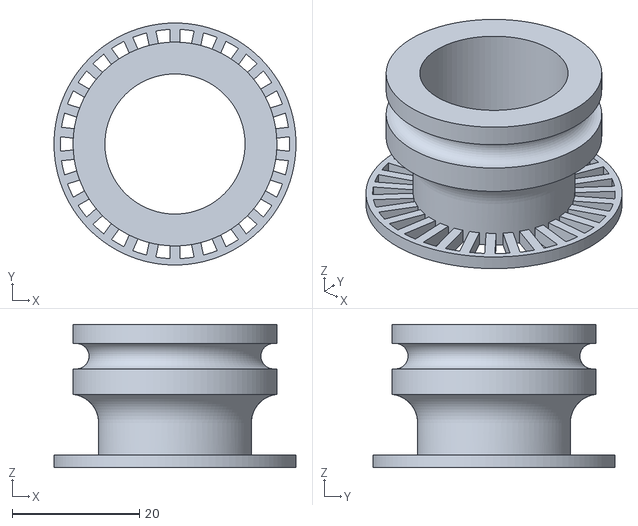
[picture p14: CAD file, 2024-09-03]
Filamentsensor/FilamentRunoutSensorwheel.stl
38.0 x 38.0 x 22.5

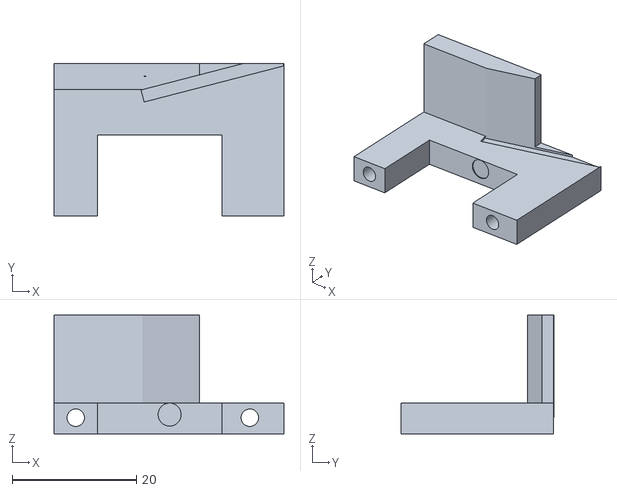
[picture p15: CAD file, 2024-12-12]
nozzlecam/stroboscope_miuzei_mirror.stl
37.0 x 24.5 x 19.1

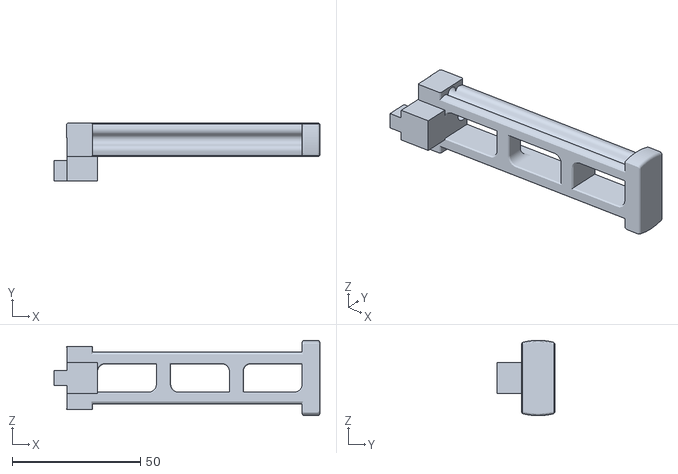
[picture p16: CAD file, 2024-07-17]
Spool/horizontal_spool_holder_82mm.stl
103.7 x 22.5 x 29.4

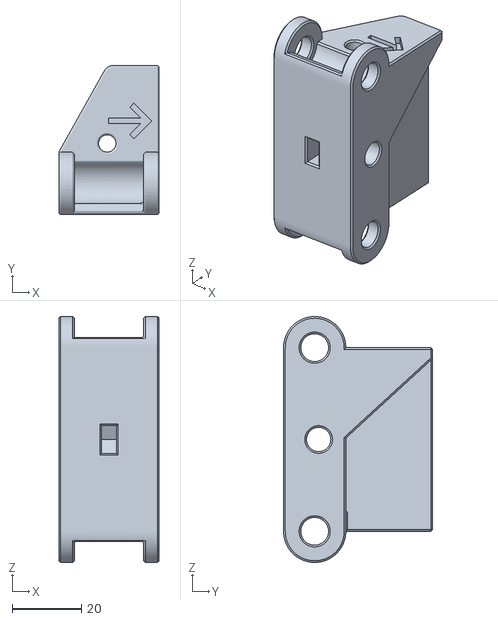
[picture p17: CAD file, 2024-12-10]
toolchanger_servo_linearactuator/syringepump/Pump Carriage Sled v51.stl
29.0 x 43.0 x 71.0

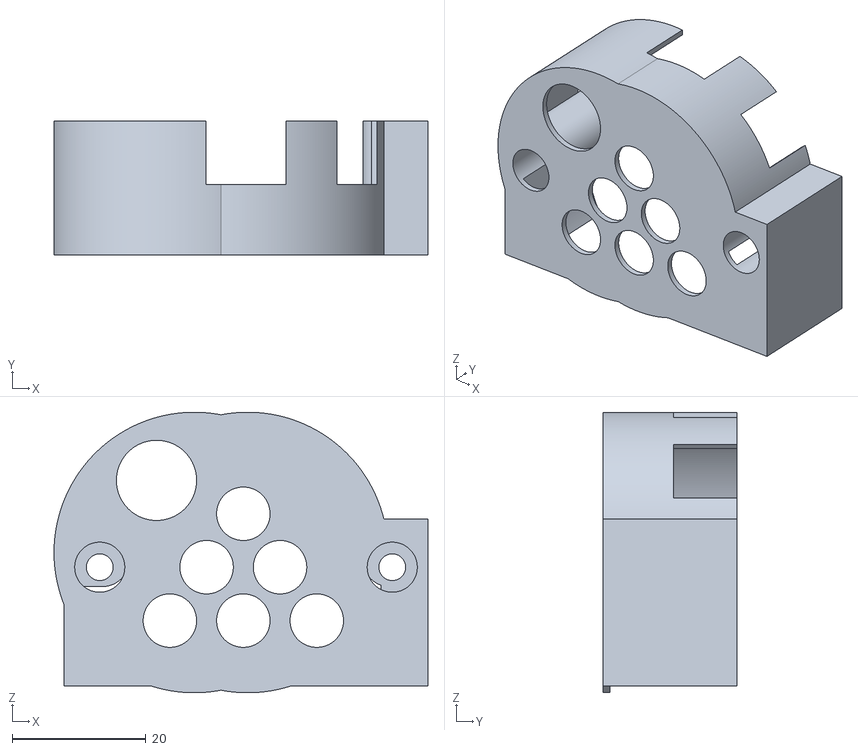
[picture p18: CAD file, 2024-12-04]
Toolhead/ebb36_cover_mod.stl
56.0 x 20.0 x 42.0

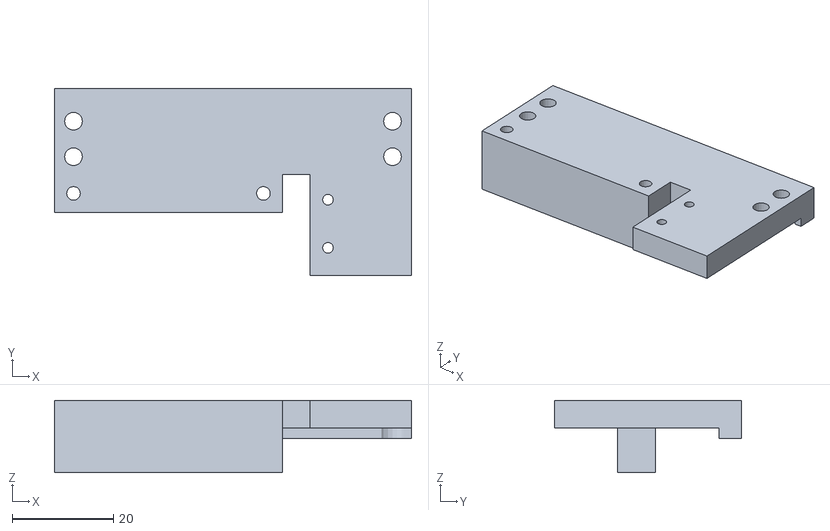
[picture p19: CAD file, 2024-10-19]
Toolhead/MG995_Servo_Linear_Actuator/files/sled_bottom.stl
70.5 x 37.0 x 14.3

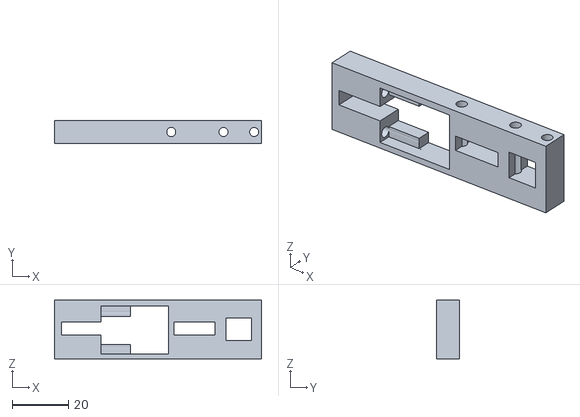
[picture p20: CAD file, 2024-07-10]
ToolLock/lock-body-slider x 2.stl
73.4 x 8.00 x 20.8

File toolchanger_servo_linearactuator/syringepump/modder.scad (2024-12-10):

//syringe_1ml_stack_1piece_multichannel_clamp();
//iverntech_pump_slider_plate_connect_multichannel();
difference(){union(){
//translate([41.9,-5-7,42.5])rotate([180,-90,90])import("pump_plunger_clamp.stl");
translate([41.9,-5-4,42.5])rotate([180,-90,90])iverntech_pump_slider_plate_connect_multichannel();
color("pink")import("pump_cover_slide_v51.stl");
}
translate([-3+0.5,34+4-4,-6])#cube([3.3-1.2,40,12]);
}

module pump_base(){
difference(){
rotate([90,0,0])import("pump_base_v51.stl");
translate([-14,28,-10])#cylinder(r=4/2,h=60,$fn=300);
translate([-14,28,3])#cylinder(r=8/2,h=60,$fn=300);
translate([-14,28-57,-10])#cylinder(r=4/2,h=60,$fn=300);
translate([-14,28-57,3])#cylinder(r=8/2,h=60,$fn=300);

translate([68,0,0]){
translate([-14,28,-10])#cylinder(r=4/2,h=60,$fn=300);
translate([-14,28,3])#cylinder(r=8/2,h=60,$fn=300);
translate([-14,28-57,-10])#cylinder(r=4/2,h=60,$fn=300);
translate([-14,28-57,3])#cylinder(r=8/2,h=60,$fn=300);
}

translate([-72,0,0]){
translate([-14,28,-10])#cylinder(r=4/2,h=60,$fn=300);
translate([-14,28,3])#cylinder(r=8/2,h=60,$fn=300);
translate([-14,28-57,-10])#cylinder(r=4/2,h=60,$fn=300);
translate([-14,28-57,3])#cylinder(r=8/2,h=60,$fn=300);
}

}
}

module syringe_1ml_stack_1piece_multichannel_clamp(){
difference(){union(){
/*
*/
//clamp part
translate([-0.3-14,0+146-2,-0.8])
translate([-110+54.5+6-14,-81.5+1.5+40+6.6+3.5-14.5,16+15+6+3])cube([5,6.5,35-15-4-3]);
translate([-0.3-14-(8*14)-3.5,0+146-2,-0.8])
translate([-110+54.5+6-14,-81.5+1.5+40+6.6+3.5-14.5,16+15+6+3])cube([5,6.5,35-15-4-3]);
for(i=[0:7]){
//color("")translate([-85-(i*14),105.5,44])rotate([-0,0,-90])syringe_1ml_plungerclip_1piece();
//translate([-183+(i*14),170,44])rotate([0,90,90])syringe_1ml();
translate([0-42.5-(i*14),-4+230-80-2,0])iverntech_pump_slider_plate_connect_multichannel();
}
}
translate([-77.5-0.5,100-0.5,50-4])rotate([90,90,0])cylinder(r=3.8/2,h=100);
translate([-77.5-0.5,130,50-4])rotate([90,90,0])cylinder(r=2.8/2,h=100);
translate([-77.5-(8*14)-0.5,100-0.5,50-4])rotate([90,90,0])cylinder(r=3.8/2,h=100);
translate([-77.5-(8*14)-0.5,130,50-4])rotate([90,90,0])cylinder(r=2.8/2,h=100);
for(i=[0:7]){
//translate([18-(i*14),0,-8])cylinder(r=3.7/2,h=40);
translate([-14,0,0]){
translate([-77.5-(i*14)-0.5,100-0.5,50-4])rotate([90,90,0])cylinder(r=3.8/2,h=100);
translate([-77.5-(i*14)-0.5,130,50-4])rotate([90,90,0])cylinder(r=2.8/2,h=100);
}
translate([-77.5-0.5,100-0.5,50-4])rotate([90,90,0])cylinder(r=3.8/2,h=100);
translate([-77.5-0.5,130,50-4])rotate([90,90,0])cylinder(r=2.8/2,h=100);
translate([-77.5-(8*14)-0.5,100-0.5,50-4])rotate([90,90,0])cylinder(r=3.8/2,h=100);
translate([-77.5-(8*14)-0.5,130,50-4])rotate([90,90,0])cylinder(r=2.8/2,h=100);
}
}
}

module iverntech_pump_slider_plate_connect_multichannel(){
translate([-0.3,0,-0.8])difference(){
union(){
translate([-110+54.5+6-3,-81.5+1.5+40+6.6+3.5-14.5,16+15+6+3])cube([22+5-12+3,6.5,35-15-4-3+8]);
}
translate([-110+59+5.3+4.5-1,-81.5+1.5+146,36-3.4+10.25+2])rotate([90,90,0])cylinder(r=3.7/2,h=200); 

//#translate([-110+59+5.3+4.5-1+4.5+3,-81.5+1.5+146,36-3.4+10.25+2+2])rotate([90,90,0])cylinder(r=2.8/2,h=200);
for(i=[0:30]){
translate([-110+59+5.3+4.5-1,-81.5+1.5+146-4-1.5-103.4,36-3.4+10.25+2+i])rotate([90,90,0])cylinder(r=10.5/2,h=1.5);
translate([-110+59+5.3+4.5-1,-81.5+1.5+146-4-1.5-7,36-3.4+10.25+2+i])rotate([90,90,0])cylinder(r=4.5/2,h=100);
}
}
}

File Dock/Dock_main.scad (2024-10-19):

include<../gantry/tslot.inc.scad>
include<dock_oozeshield_mount.scad>


//dock_main_mod_openscad_servo_linearactuator();
//dock_main_mod();
//dock_main_mod_openscad();
//import("Dock_main_exp_2in1.stl");

//translate([-55,100,90-0.3])rotate([90,0,0])tslot20(200);

//translate([60,0+5,-2+2.5])dock_main_mod();
//import("/Users/richard/Documents/voron/Trident/daksh_clean/Dock/Dock_main_exp_2in1.stl");

//translate([4.4,100,90.25])rotate([90,0,0])tslot20(300);

//translate([80-16.5,-36.5,23])rotate([0,0,90])dock_oozeshield();
//translate([80-16.5-48,-36.5-5,23])rotate([0,0,90])dock_oozeshield();

//translate([-52+202+60.1,20-80+84.65,120-2.8])color("pink")rotate([0,90,-90])rotate([0,0,-90])tslot20innerbracket_stable();

/*
translate([2,12,0-4]){
translate([50,-50,10])import("ultimate_nozzle_wiper_base.stl");
translate([54.6,-50+7.30,30+2])#cylinder(r=7.8/2,h=12,$fn=300);
translate([54.6,-50+7.30,30])#cylinder(r=7.8/2,h=12,$fn=300);
}
*/


//mod_nozzle_wiper();

module tslot20innerbracket_stable(){
   

 //bottom corner support
   translate([180,2,0])   rotate([0,90,-270]){  
   /*
   difference(){
   #translate([25,0,0])cube([15+0,5+0,20+0]);
    #translate([19+13,15,10])    rotate([90,0,0])    cylinder(r=5.7/2,h=50, $fn=300);
   }
   */
   difference(){
   union(){
   translate([-10+0,0,-10])cube([15+0,30+0,40+0]);
   translate([-10,4,0])cube([13,5,70]);
   //#translate([0,0,0])cube([30+0,30+0,20+0]);
   }
   //translate([27,0,-2])   cube([10,5,25]);
   //translate([0,27,-2])   #cube([10,5,25]);
   //#translate([0,30,25])   rotate([180,0,45])   cube([30,50,30]);
   translate([5+6,5,5])
   cube([20,20,9.5]);
   translate([-5-42+37+4,20-4.34,10-13.3])rotate([0,90,0])cylinder(r=9.5/2,h=50, $fn=300);
   translate([-5-42,20-4.34,10-13.3])rotate([0,90,0])cylinder(r=5.5/2,h=80, $fn=300);
   translate([-5-42+37+4,20-4.34,10-13.3+24])rotate([0,90,0])cylinder(r=9.5/2,h=80, $fn=300);
   translate([-5-42,20-4.34,10-13.3+24])rotate([0,90,0])cylinder(r=5.5/2,h=80, $fn=300);

    //#translate([19,15,10])    rotate([90,0,0])    cylinder(r=5.7/2,h=50, $fn=300);
    translate([19-22,35,10])    rotate([90,0,0])    cylinder(r=5.7/2,h=50, $fn=300);
    translate([19-22,54,10])    rotate([90,0,0])    cylinder(r=9.7/2,h=50, $fn=300);
    #translate([19-22-13.5+13.5,35,65.4])    rotate([90,0,0])    cylinder(r=3.7/2,h=50, $fn=300);
   }
    //translate([-2,0,7.5])   # cube([5,13,5]);
   }
}




module test_dock(){

#color("pink")import("/Users/richard/Documents/voron/Trident/daksh_clean/Dock/daksh_clean/Dock/Dock_main_exp_2in1.stl");

}

module dock_main_mod(){
//color("orange")translate([-59.78,0,-0.25])
color("pink")import("Dock_main.stl");
difference(){
union(){
//color("orange")translate([59.78,0,-0.25])import("../Dock/dock-mount.stl");
translate([0,0.1,0])import("dock-mount.stl");
color("pink")import("/Users/richard/Documents/voron/Trident/daksh_clean/Dock/Dock_main.stl");
//import("dock-mount.stl");
//#translate([-20,3.05,133.95])rotate([0,90,0])cylinder(r=4.15/2,h=120,$fn=300);
//translate([-20,3.05,133.95-55.35])rotate([0,90,0])cylinder(r=4.15/2,h=120,$fn=300);
translate([-35+4,3.0,133.95-7.4])rotate([0,90,0])cylinder(r=5.5/2,h=30,$fn=300);
translate([-35+4,3.0+0.25,133.95-7.4-41.74])rotate([0,90,0])cylinder(r=5.5/2,h=14,$fn=300);
translate([-60,0,2]){
translate([30-0.11,-3.186,87])cube([25,12.692,35]);
translate([30-0.11-2,-3.186,87-3])cube([10,12.692,8.7]);
translate([30-0.11-2,-3.186,87-3-14.3])cube([1.4,12.692,15]);
translate([30-0.11-2,-3.186,87+30])cube([10,12.692,5]);
translate([30-0.11-2,-3.186,87+30])cube([1.4,12.692,24.3]);
}

translate([0,0,0]){
translate([0,0,0]){
translate([12.45,5.06,60.95])rotate([90,0,0])cylinder(r=6.5/2,h=8.3,$fn=300);
translate([0,0,78.6])
translate([12.45,5.06,60.95])rotate([90,0,0])cylinder(r=6.5/2,h=8.3,$fn=300);
translate([-38.75,0,81.2])
translate([12.45,5.06,60.95])rotate([90,0,0])cylinder(r=8.5/2,h=8.3,$fn=300);
translate([-38.75,0,81.2+14])
translate([12.45,5.06,60.95])rotate([90,0,0])cylinder(r=5.5/2,h=8.3,$fn=300);
translate([-39,0,9.4])
translate([12.45,5.06,60.95])rotate([90,0,0])cylinder(r=8.5/2,h=8.3,$fn=300);
}
}
translate([-39,0,9.4]){
translate([12.45,5.06-5.6,60.95])rotate([90,0,0])cylinder(r=8.1/2,h=2.7,$fn=300);
translate([12.45,5.06-5.6,60.95-6.5])rotate([90,0,0])cylinder(r=5.1/2,h=2.7,$fn=300);
}
translate([-60-2,0,2]){
translate([30-0.11-2,-3.186+4,87-3-14.3+2])cube([1.4+1,12.692-8,17]);
}
translate([-38.75,0,81.2])translate([12.45,5.06-5.6,60.95])rotate([90,0,0])cylinder(r=8.1/2,h=12.7,$fn=300);
translate([0,0,78.6])translate([12.45,5.06-5.6,60.95])rotate([90,0,0])cylinder(r=6.1/2,h=2.7,$fn=300);
translate([12.45,5.06-5.6,60.95])rotate([90,0,0])cylinder(r=6.1/2,h=2.7,$fn=300);
translate([-60-0.,0,2-2.5]){
translate([35-1.56+0.3,-10+6.6,124.96-3-5])rotate([-90,0,0])color("silver")cylinder(r2=5.0/2,r1=10/2,h=4,$fn=300);
translate([35-1.56+0.3,-10,124.96-3-5])rotate([-90,0,0])color("silver")cylinder(r=5.0/2,h=32,$fn=300);
translate([35-1.56+0.3,-10+6.6,82.96+3+5])rotate([-90,0,0])color("silver")cylinder(r2=5.0/2,r1=10/2,h=4,$fn=300);
translate([35-1.56+0.3,-10,82.96+3+5])rotate([-90,0,0])color("silver")cylinder(r=5.0/2,h=32,$fn=300);
}
translate([-60-0.,0,2]){
translate([35-1.56+0.3+12,-10,124.96-3-6])rotate([-90,0,0])color("silver")cylinder(r=4.8/2,h=32,$fn=300);
translate([35-1.56+0.3+12,-10,124.96-3-30])rotate([-90,0,0])color("silver")cylinder(r=4.8/2,h=32,$fn=300);
}
}
translate([-35+4-6,3.0,133.95-7.4])rotate([0,90,0])cylinder(r=3.9/2,h=46,$fn=300);
translate([-35+4-6,3.0,133.95-7.4-41.74])rotate([0,90,0])cylinder(r=3.9/2,h=24,$fn=300);
translate([-35+4-6,3.0,133.95-7.4+7.4])rotate([0,90,0])cylinder(r=3.95/2,h=86,$fn=300);
translate([-35+4-6,3.0,133.95-7.4-41.74-6.3])rotate([0,90,0])cylinder(r=3.95/2,h=74,$fn=300);

// magnets
translate([-38.75,0,81.2])translate([12.45,5.06-5.6,60.95])rotate([90,0,0])cylinder(r=8.1/2,h=2.7+1,$fn=300);
translate([-38.75,0,81.2-34.7])translate([12.45,5.06-5.6,60.95])rotate([90,0,0])cylinder(r=6.5/2,h=2.7+1,$fn=300);
translate([-38.75,0,81.2-34.7])translate([12.45,5.06-5.6,60.95+23])rotate([90,0,0])cylinder(r=8.1/2,h=2.7+1,$fn=300);

translate([-39,0,9.4])
translate([12.45,5.06-5.6,60.95])rotate([90,0,0])cylinder(r=8.1/2,h=2.7+20,$fn=300);

}

difference(){union(){
translate([2.74,-0.15,136.2])cylinder(r=4/2,h=7.3,$fn=300);
translate([2.74,-0.15+7,136.2])cylinder(r=4/2,h=7.3,$fn=300);
translate([2.74,-0.15,136.2-13])cylinder(r=4/2,h=7.3,$fn=300);
translate([2.74,-0.15+7,136.2-13])cylinder(r=4/2,h=7.3,$fn=300);

}
translate([2.74,-0.15,136.2-14])cylinder(r=2.9/2,h=22,$fn=300);
translate([2.74,-0.15+7,136.2-14])cylinder(r=2.9/2,h=22,$fn=300);
}


//dock_main();

}











module dock_main_mod_openscad_servo_linearactuator(){
//color("orange")translate([-59.78,0,-0.25])
//color("pink")import("/Users/richard/Documents/voron/Trident/daksh_clean/Dock/Dock_main.stl");
//translate([0,0.1,0])import("dock-mount.stl");
//translate([-60,0-5.,-0.4])import("Dock_main_exp_2in1.stl");

difference(){
translate([-60,0,2]){
translate([30-0.11-18.18-0.4+18.58-0.9+12+25,-3.186-0,87+25.8-47.1+2.2-15.3])cube([16,12.692,10+70]);
}
translate([-35+4-6,3.0,133.95-7.4+7.4])rotate([0,90,0])cylinder(r=4.05/2,h=86,$fn=300);
translate([-35+4-6,3.0,133.95-7.4-41.74-6.3])rotate([0,90,0])cylinder(r=4.05/2,h=74,$fn=300);
}
difference(){
union(){
//color("orange")translate([59.78,0,-0.25])import("../Dock/dock-mount.stl");
//translate([0,0.1,0])import("dock-mount.stl");
//#color("pink")import("/Users/richard/Documents/voron/Trident/daksh_clean/Dock/Dock_main.stl");
//import("dock-mount.stl");
//#translate([-20,3.05,133.95])rotate([0,90,0])cylinder(r=4.15/2,h=120,$fn=300);
//translate([-20,3.05,133.95-55.35])rotate([0,90,0])cylinder(r=4.15/2,h=120,$fn=300);
translate([-35+4,3.0,133.95-7.4])rotate([0,90,0])cylinder(r=5.5/2,h=30,$fn=300);
translate([-35+4,3.0+0.25,133.95-7.4-41.74])rotate([0,90,0])cylinder(r=5.5/2,h=14,$fn=300);

translate([-60,0,2]){
translate([30-0.11-18.18-0.4+18.58-0.9+12+6,-3.186,87+25.8-47.1+2.2-15.3+88-88-10])cube([5,12.692,20]);

translate([30-0.11-18.18-0.4+18.58-0.9+18,-3.186,87+25.8-47.1+2.2-15.3+88])cube([10,12.692,20]);
//#translate([30-0.11-18.18-0.4+18.58-0.9+12,-3.186-0,87+25.8-47.1+2.2-15.3+98])cube([12,12.692,10]);
translate([30-0.11-18.18-0.4+18.58-0.9+12+25,-3.186-0,87+25.8-47.1+2.2-15.3])cube([16,12.692,10+70]);
translate([30-0.11-18.18-0.4+18.58,-3.186,87+25.8-47.1+2.2-15.3])cube([25-5+30+12+5,12.692,24.9+64.2]);
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

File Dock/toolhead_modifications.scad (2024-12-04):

//include<../ToolLock/printable_lm3uu.scad>
//include<../ToolLock/printmgn12.scad>
include<../gantry/tslot.inc.scad>

include<../Dock/Dock_main.scad>

include <rack_renamed.scad>
include <microfluidics/multichannel_cameramount.scad>
include <holder_half.scad>


//toolhead_bottom_fix_improved_bambu_coolingfan_attach();
//bambulab_extruder();

//color("pink")import("ebb36-cover.stl");

ebb36_cover();

module ebb36_cover(){
difference(){union(){
translate([12,0-44.4-15.5,186.5+1.2])rotate([-90,0,0])cylinder(r=8/2,h=20,$fn=300);
hull(){
translate([12-43,0-44.4-15.5,186.5+1.2])rotate([-90,0,0])cylinder(r=8/2,h=20,$fn=300);
translate([12-43-3,0-44.4-15.5,186.5+1.2])rotate([-90,0,0])cylinder(r=8/2,h=20,$fn=300);
//translate([12-43-3.5,0-44.4-15.5,186.5+4.2])rotate([-90,0,0])cylinder(r=8/2,h=20,$fn=300);
}
}
translate([12+0.4,0,186.6])rotate([90,0,0])cylinder(r=4/2,h=100,$fn=300);
translate([12-43.4,0,186.6])rotate([90,0,0])cylinder(r=4/2,h=100,$fn=300);
translate([12+0.4,-50,186.6])rotate([90,0,0])cylinder(r=7.5/2,h=100,$fn=300);
translate([12-43.4,-50,186.6])rotate([90,0,0])cylinder(r=7.5/2,h=100,$fn=300);
}
difference(){
union(){
translate([12-48.75,0-59.9,186.5-17.7])cube([54.5,20,25]);
translate([12-48.75+27.5,0-59.9,186.5-17.7+20])rotate([-90,0,0])cylinder(r=(37+5)/2,h=20,$fn=300);
translate([12-48.75+27.5-8,0-59.9,186.5-17.7+20])rotate([-90,0,0])cylinder(r=(37+5)/2,h=20,$fn=300);
translate([12,0-44.4,186.5+1.2])rotate([90,0,0])cylinder(r=8/2,h=15.5,$fn=300);
translate([12-43,0-44.4,186.5+1.2])rotate([90,0,0])cylinder(r=8/2,h=15.5,$fn=300);
}
translate([0,1,0])hull(){
translate([12-48.75+27.5,0-59.9,186.5-17.7+20])rotate([-90,0,0])cylinder(r=(37+3)/2,h=24,$fn=300);
translate([12-48.75+27.5-8,0-59.9,186.5-17.7+20])rotate([-90,0,0])cylinder(r=(37+3)/2,h=24,$fn=300);
translate([12-48.75+27.5,0-59.9,186.5-17.7+20-10])rotate([-90,0,0])cylinder(r=(37+3)/2,h=24,$fn=300);
translate([12-48.75+27.5-6,0-59.9,186.5-17.7+20-10])rotate([-90,0,0])cylinder(r=(37+3)/2,h=24,$fn=300);
}
//translate([12-48.75+27.5-6-14,0-59.9,186.5-17.7+33])rotate([-90,0,0])cylinder(r=(15)/2,h=24,$fn=300);
translate([12+0.4,-50,186.6])rotate([90,0,0])cylinder(r=7.5/2,h=100,$fn=300);
translate([12-43.4,-50,186.6])rotate([90,0,0])cylinder(r=7.5/2,h=100,$fn=300);
translate([12+0.4,0,186.6])rotate([90,0,0])cylinder(r=4/2,h=100,$fn=300);
translate([12-43.4,0,186.6])rotate([90,0,0])cylinder(r=4/2,h=100,$fn=300);
translate([12-43.4+16+11/2-13,0,186.6+8+5])rotate([90,0,0])cylinder(r=12/2,h=100,$fn=300);
translate([12-43.4+16+11/2,0,186.6+8])rotate([90,0,0])cylinder(r=8/2,h=100,$fn=300);
translate([12-43.4+16,0,186.6])rotate([90,0,0])cylinder(r=8/2,h=100,$fn=300);
translate([12-43.4+16+11,0,186.6])rotate([90,0,0])cylinder(r=8/2,h=100,$fn=300);
translate([12-43.4+16-11/2,0,186.6-8])rotate([90,0,0])cylinder(r=8/2,h=100,$fn=300);
translate([12-43.4+16-11/2+11,0,186.6-8])rotate([90,0,0])cylinder(r=8/2,h=100,$fn=300);
translate([12-43.4+16-11/2+22,0,186.6-8])rotate([90,0,0])cylinder(r=8/2,h=100,$fn=300);
translate([12-20,0-59.9+10.5,186.5-17.7+13])rotate([0,-40,0])cube([120,10,10]);
#translate([12-20+4.5,0-59.9+10.5,186.5-17.7+13])rotate([0,-90,0])cube([120,10,12]);
}
}

/*

translate([20,20,0]){
dowel_pin(4.2);
translate([0,0-0.0,-2.])m5nut(9.45);
//translate([0,0,-2])m5nut(9); //good for bottom
//translate([0,0,-2])m5nut(9.12); //good for top
}
*/

/*
translate([80,-54.5+14.5,155.9-86.17])rotate([0,90,0])rotate([0,0,30]){
translate([20,20,0]){
dowel_pin(4.2);
//translate([0,0,-2])m5nut(9.38);
//translate([0,0,-2])m5nut(9); //good for bottom
translate([0,0,-2])m5nut(9.12); //good for top
}
}

*/

//mgn12_block();


//toolchange_openscad();
//translate([0,0,-1])toolhead_top_1_clone_openscad();
//parts_cooling_fan_screwattach_ring();

//translate([0,0,20])parts_cooling_fan_just2sides();

//color("lime")import("toolhead_bottom_fix_improved_bambu_coolingfan_attach.stl");
//toolhead_bottom_fix_improved_bambu_coolingfan_attach();
//translate([-20+1.8-1,1.539,-6.6])translate([200,0,225.5])rotate([0,180,0])mgn12_hole();
//import("toolhead_top_1_fix_nom3fittings_endstop_mechanicalwire.stl");

//translate([59.8,-0.15,0])toolheadtop2_fixed_nom3fittings_endstop();

//translate([12,0,0])toolchanger_linearactuator();
//ebb36_mount();
//translate([32,-22-2,45-1.25])scale([0.5,0.5,1])rotate([0,0,180])import("DuctIVSingle_base.stl");
//parts_cooling_fan_screwattach();

/*
difference(){
rotate([0,0,-20])import("DuctIVSingle.stl");
translate([-15,-30,-4])cube([50,80,20]);
}
*/
//ebb_mount();

/*
difference(){
import("servo_linear_assy_servo_holder_bottom.stl");
translate([24.5,0,-2])cube([6,100,5]);
}
*/

//translate([60+5-2+0-20,-2+2-46.5,8.8])rotate([0,0,180])import("parts-cooling-fan.stl");
//translate([60+5-2+0-20,-2+2-46.5,45])cube([20,20,5]);
//parts_cooling_fan_screwattach();
//color("lime")import("toolhead_bottom_fix_improved_bambu_coolingfan_attach.stl");
//import("toolhead_top_1_fix_nom3fittings_endstop_mechanicalwire.stl");
//translate([59.8,-0.15,0])toolheadtop2_fixed_nom3fittings_endstop();
//translate([0,0+5,-2+2.5])color("pink")import("../Dock/Dock_main_exp_2in1.stl");

//translate([60,0+5,-2+2.5])dock_main_mod_openscad();
//translate([60,0+5,-2+2.5])dock_main_mod();
//import("/Users/richard/Documents/voron/Trident/daksh_clean/Dock/Dock_main_exp_2in1.stl");


//dock_main_mod_openscad();
//translate([60,0+5,-2+2.5])dock_main_mod_openscad_servo_linearactuator();
//translate([5,200,90])rotate([90,0,0])tslot20(500);
//translate([12,0,0])toolchanger_linearactuator();

//holder_half_top();
//holder_half_bottom();


//color("lime")translate([64-1.5,-20,70-5])rotate([-90,0,90])import("servo_linear_assy_servo_holder_top.stl");
//color("")translate([64-1.5-61.5+1.5,-20+20,0])rotate([-0,0,0])holder_half_bottom();
//color("")translate([64-1.5-61.5+1.5,-20+20,0])rotate([-0,0,0])holder_half_top();

module bottom_filament_switch(){

translate([0.25,0,0]){
translate([60-2,-40+2,118.5-10])color("red")sphere(r=6.1/2, $fn=300);
translate([60-2,-40+2-0,118.5-10])color("red")rotate([-90,0,0])cylinder(r=6.1/2,h=6+0,$fn=300);
//translate([60-2-2.8-0,-40+2+4.2,118.5-4.8-20])color("red")cube([6+0,15+0,13.08+10]);
translate([60-2-2.8-0,-40+2+4.2,118.5-4.8-10-1.5])color("red")cube([6+0+6+5,15+0-2+0.5,13.08+3]);

translate([0,0.8,0]){
translate([60-2-30,-40+2+9,118.5-1.5-10])color("")rotate([0,90,0])cylinder(r=2.1/2,h=30,$fn=300);
translate([60-2-30,-40+2+9,118.5-1.5+6.5-10])color("")rotate([0,90,0])cylinder(r=2.1/2,h=30,$fn=300);
translate([60-2,-40+2+9,118.5-1.5+6.5-10])color("")rotate([0,90,0])cylinder(r=4/2,h=60,$fn=300);
translate([60-2,-40+2+9,118.5-1.5-10])color("")rotate([0,90,0])cylinder(r=4/2,h=60,$fn=300);
}
}


}





module holder_half_top(){
color("pink")translate([64-1.5,-19.5,70-5])rotate([-90,0,90])difference(){
holder_half();
translate([-18+1+41.5,0,-5])cube([5,30+100,10]);
translate([-18+1,0,-5])cube([30,30+100,60]);
translate([-18+1+58,10,-5])cube([30,30+100,60]);
}
}

module holder_half_bottom(){
color("lightblue")translate([64-1.5,-19.5+54,70-5-70])rotate([90,0,-90])difference(){
holder_half();
translate([-18+1+41.5,0,-5])cube([5,30+100,10]);
translate([-18+1,0+20,-5])cube([30,30+100,60]);
translate([-18+1+58,10-30,-5])cube([30,30+100,60]);
}
}


//toolchanger_linearactuator();


//color("lime")translate([64-1.5,-20,70-5])rotate([-90,0,90])import("servo_linear_assy_servo_holder_top.stl");

module toolchanger_linearactuator(){

servo_linear_actuator_rack_toolchanger();
ebb_mount();

toolchange_openscad();
translate([0,-55+4,63]){
color("lime")translate([64-1.5,-20,70-5])rotate([-90,0,90])import("servo_linear_assy_servo_holder_top.stl");
//color("lime")translate([64-1.5,-20,70-5])rotate([-90,0,90])holder_half_bottom();
color("")translate([64-1.5-61.5+1.5,-20+20,0])rotate([-0,0,0])holder_half_bottom();
color("")translate([64-1.5-61.5+1.5,-20+20,0])rotate([-0,0,0])holder_half_top();


color("black")translate([64,-20,70-5])rotate([-90,0,90])translate([37,14-0,-12])rotate([0,0,90])servo();
//color("lime")translate([64,-20,70-5])rotate([-90,0,90])import("servo_linear_assy.stl");
//translate([70-8.5,70.7,34.5])rotate([0,180,90])
color("pink")translate([60+6,-7.5-5,-6+20])rotate([0,-90,0])import("pinion.stl");
translate([37-1.0,35,65])rotate([0,90,0])mirror([0,1,0]){
translate([0,0,-0.0])color("lightblue")import("sled_bottom_no_limit_switch_protrusion.stl");
//color("peru")translate([0,-7.5,-6])import("sled_cap.stl");
}
}
}


module servo_linear_actuator_rack_toolchanger(){
translate([0,0,20]){
translate([35,-65+4,40])mirror([0,1,0])rotate([0,-90,0])rack();
translate([25,-35,37.5+27])rotate([0,180,0])pipette_p1000_noextrusion(8.3,0,"y",10);
}
}
//multichannel_cameramount_tipholder();
//translate([60,0,-2])dock_main_mod();
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

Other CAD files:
Toolhead/servo_linear_assy_servo_holder_bottom.stl
toolchanger_servo_linearactuator/holder_half_top.stl
Dock/nema14_dock_support.stl
Filamentsensor/FilamentRunoutSensorcase_toolchanger.stl
Spool/spool_holder_82mm.scad
Dock/adjust_dock_oozeshield_mount.stl
Dock/dock-mount.stl
Dock/dock-wireloom-extrusion-holder.stl
Dock/dock_oozeshield_mount.scad
Dock/dock_oozeshield_mount.stl
Dock/dock_oozeshield_mount_mod.stl
Dock/dock_wireloom.scad
Dock/dock_wireloom_setscrew.stl
Dock/tslot20innerbracket_stable.stl
Endstop/xyendstop.scad
Filamentsensor/FilamentRunoutSensorcase.stl
Filamentsensor/belt.scad
Filamentsensor/belt.stl
Filamentsensor/filament_sensor.scad
Gantry/xyendstop.scad
Gantry/xyendstop.stl
Spool/spool_holder_82mm.stl
ToolLock/MGN12_Linear_Guide.stl
ToolLock/MGN12_Linear_Guide_centtocent_shorter.stl
ToolLock/carriage-mgn12-integrated--belt-groove.stl
ToolLock/carriage_mod.scad
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

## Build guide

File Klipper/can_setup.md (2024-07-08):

# CAN setup #

CAN makes it straightforward to add more devices. This is done by using an ethernet cable that has twisted pair cables, one of which is used for the CAN connection (High and Low) and the others are grouped (3 for the 24V and the other 3 grouped for ground. 

The recipe for setting up the firmware for both the BTT EBB36 and EBB42 CAN device boards and the CAN bus adaptor (BTT U2C v2.1) are derived from KB3d - https://wiki.kb-3d.com/

## BTT U2C v2.1 setup ## 

btt_u2c_brd

A good DIN mount is posted here: https://github.com/VoronDesign/VoronUsers/tree/main/printer_mods/Electroleon/U2C_Mounting. 

After connecting the U2C board to the Raspberry Pi using, usb-c, type lsusb to see if it is being recognized. 

lsusb_sees_u2c_brd

If its working then you need to create a can0 file like so:
``` sudo nano /etc/network/interfaces.d/can0 ```

Then add this into the file:

```
allow-hotplug can0
  iface can0 can static
  bitrate 500000
  up ip link set can0 txqueuelen 1024
```

Then reboot the Pi, and check if it is working using ```ifconfig can0```, you should see something like this:

<img width="623" alt="ifconfig_can0_resp" src="https://github.com/htsrjdrouse/daksh-toolchanger-v2/assets/1452651/951500f7-a78d-4f62-962a-91bad47a1557">

## BTT EBB36/42 setup ## 

Background info about these boards are posted on the BTT github: https://github.com/bigtreetech/EBB. Initially, you have to flash the firmware to set up CAN. To do that you need to connect to you Pi, using usb-c and you have to install a jumper to power up the EBB board like so:

<img width="702" alt="EBB_jumper" src="https://github.com/htsrjdrouse/daksh-toolchanger-v2/assets/1452651/70f0cc18-a6d0-4de5-adb3-cea8dac43846">

SSH into your Pi, and type lsusb to see if you can see it:

<img width="450" alt="lsusb_ebb" src="https://github.com/htsrjdrouse/daksh-toolchanger-v2/assets/1452651/c995113b-39c1-4f2a-95d2-8e1d904faef2">

If the device is showing you have to put it into DFU mode, you have to press/hold boot button then press the reset button. Afterwards type lsusb again, and see if the board is not in DFU mode like so:

<img width="534" alt="lsusb_ebb_dfu-mode" src="https://github.com/htsrjdrouse/daksh-toolchanger-v2/assets/1452651/1e13c087-9e15-4726-b2d5-178415db23e6">

Now you have to prepare the firmware for bootloading, first by downloading the CanBoot code like so:

``` cd ~
git clone https://github.com/Arksine/CanBoot
```

After downloading, cd into that directory and run ```make menuconfig```, make sure you match the CAN bus speed. 

make_menuconfig_a

Now compile the bootloader

```make clean
make
```

Then load it onto the board like so:

```sudo dfu-util -a 0 -D ~/CanBoot/out/canboot.bin --dfuse-address 0x08000000:force:mass-erase:leave -d 0483:df11```

It should look something like this:

<img width="543" alt="looks_after_loading_bootloader" src="https://github.com/htsrjdrouse/daksh-toolchanger-v2/assets/1452651/a0e8c918-325a-4872-90aa-e7a7c62e3112">

After successful flashing, you can now upload firmware via CAN (rather then USB), now you need to install a jumper to enable terminating resistor like so and remove the jumper that powered the EBB using USB:

<img width="648" alt="terminating_resistor_no_usb_power" src="https://github.com/htsrjdrouse/daksh-toolchanger-v2/assets/1452651/cfaea081-7c8d-47d3-b2f0-24c9204375d3">

Now connect the EBB board via CAN, and verify its being recognized by typing ```python3 ~/CanBoot/scripts/flash_can.py -i can0 -q```

<img width="456" alt="flash_can" src="https://github.com/htsrjdrouse/daksh-toolchanger-v2/assets/1452651/40d8e720-977f-45c1-8532-9021dc8d826b">

After you are able to detect, now you need to build Klipper. 

```cd ~/klipper
make menuconfig
```

ebb_klipper

After building, flash it to the EBB like so: ```python3 ~/CanBoot/scripts/flash_can.py -i can0 -u MYUUID -f ~/klipper/out/klipper.bin``` Remember to replace MYUUID with UID detected earlier. It should look something like this:

flash_klipper

Now run klipper can bus query command to see it installed ok ```~/klippy-env/bin/python ~/klipper/scripts/canbus_query.py can0```

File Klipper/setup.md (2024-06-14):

# Set up procedure #

First, check if the TC and TD are wired correctly (TC is tool coupling and TD is tool dock). It should look like this:

sensor_test_working

And in this case, the LEDs are both on:

both_tool_leds_on

Then just run, CALC_DOCK_LOCATION tool=0 and CALC_DOCK_LOCATION tool=1, with the pins inside the dock (leave as is). It works with needing to remove the. Rather then using DOCK_TEST, you can run some gcode like this:

<code>
G1 X100 Y200 F8000
T0
M400
G1 X100 Y200 F8000
M400
KTCC_TOOL_DROPOFF_ALL
M400
G1 X100 Y200 F8000
T1
M400
G1 X100 Y200 F8000
M400
KTCC_TOOL_DROPOFF_ALL
M400
</code>

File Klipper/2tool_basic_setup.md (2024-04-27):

I am trying to figure out how to run this code and am providing some notes as I get a handle of this. There are some tool differences between the original daksh design and my version namely the optical probe sensor will be used used but instead use a detachable probe but this could still use the same pin, also (just because I accidently purchased the EBB42 instead of the EBB36), the pin designation will be different in some cases since I also am using EBB36 too. Also, instead of 4 tools, I am just going to use 2. (One of the things you need to do when installing this is that you need to move the files in the modules folder into  ~/klipper/klippy/extras/, not moving the modules directory and subdirectories, but the files in the directory/subdirectories, since they are modules typically installed from other github repos).

If you use less or more tools then just 4 (in my case I am using 2), then you need to make sure you indicate that. Here is a list of areas that may need to be modified:</li>

 1. In toolchange_management.cfg, you have this code (currently I do not know what these gcode macros do)

   ```
[gcode_macro CYCLE_ALL_TOOLS]
gcode:
     SET_GCODE_VARIABLE MACRO=STORE_TOOLHEAD_POSITION VARIABLE=bypass_toolhead_position VALUE=1
     T0
     T1
     ;T2 <- delete
     ;T3 <- delete
     ;T4 <- delete
     INITIALIZE_TOOL_USE_COUNT
     T{params.FINAL_TOOL}
     SET_GCODE_VARIABLE MACRO=STORE_TOOLHEAD_POSITION VARIABLE=bypass_toolhead_position VALUE=0

[gcode_macro TEST_TOOLS]
  gcode:
    SET_GCODE_VARIABLE MACRO=STORE_TOOLHEAD_POSITION VARIABLE=bypass_toolhead_position VALUE=1
    G28
    G0 X126 Y250
    {% for move in range(50) %}
        T0
        #KTCC_TOOL_DROPOFF_ALL
        T1
        ;T2 <- delete
        ;T3 <- delete
        ;T4 <- delete
    {% endfor %}
    T0
    SET_GCODE_VARIABLE MACRO=STORE_TOOLHEAD_POSITION VARIABLE=bypass_toolhead_position VALUE=0
```

  2. Also in crash_detection.cfg there are indications to tools 1-4 so here this file also needs to be modified:
```
[gcode_macro VARIABLES_LIST]
variable_tools:[0,1] ;changed from variable_tools:[0,1,2,3,4]
variable_active_tool:-1
variable_tc_state:0 #-1:Error, 0: Operational
variable_tc_error_code:0 # 0: No Error, 1: No Tool Attached to Carriage, 2: Tool Dock Failure, 3: Multiple Tools Attached  
variable_global_z_offset:0
variable_error_tools:[]
variable_t0_used_in_print:0
variable_t1_used_in_print:0
;variable_t2_used_in_print:0   <- delete
;variable_t3_used_in_print:0   <- delete
;variable_t4_used_in_print:0   <- delete
variable_print_status:0
variable_current_layer:0
variable_current_bed_temp:0
variable_pause_type:0 # 0: No Error, 1:ToolChanger Error 2: Filament Error

gcode:
```

  3.  I don't want to use the tool probe , so need to remove this in toolchanger.cfg, need to comment out this lines:
```
  ;SET_ACTIVE_TOOL_PROBE T={params.T} ; no setting active tool probe
```

  4. Commented this out: SET_ENCLOSURE_DEFAULT. 
This is in crash_detection.cfg and in klipper_toolchanger/pause_resume.cfg

  5. Commented out: SET_STATUS_LED_LOCK
  
Klipper/config/klipper_toolchanger/pause_resume.cfg:		SET_STATUS_LED_LOCK T={printer["gcode_macro VARIABLES_LIST"].active_tool}
Klipper/config/crash_detection.cfg:			SET_STATUS_LED_LOCK T={tool}
Klipper/config/toolchanger.cfg:  SET_STATUS_LED_LOCK T={params.T}
Klipper/config/toolchanger.cfg:    SET_STATUS_LED_LOCK T={tool}

  6. Enabled [force_move] in printer_config.cfg like so:
```   
[force_move]
enable_force_move: True
```

  7. Commented out: SET_STATUS_LED_NOT_IN_USE
Klipper/config/crash_detection.cfg:		  		SET_STATUS_LED_NOT_IN_USE T={tool}
Klipper/config/crash_detection.cfg:  	 SET_STATUS_LED_NOT_IN_USE T={tool}

  8. In status_led.cfg, I had to remove all the tool references that are not being used, including the "neopixel cled" stuff 

  9. Had to add this, ktcc_dock_move_speed = 3000 in variables.cfg

  10. Also in status_led.cfg, I commented out the enclosure stuff, like so:

```
#[gcode_macro LED_ENCLOSURE_EFFECT_STOP]
#gcode:
#   SET_LED_EFFECT EFFECT=enclosure_error STOP=1
#   SET_LED_EFFECT EFFECT=enclosure_default STOP=1

#[gcode_macro SET_ENCLOSURE_ERROR_START]
#gcode:
#      LED_ENCLOSURE_EFFECT_STOP
#      SET_LED_EFFECT EFFECT=enclosure_error  
   
#[gcode_macro SET_ENCLOSURE_DEFAULT]
#gcode:
#      LED_ENCLOSURE_EFFECT_STOP
#      SET_LED_EFFECT EFFECT=enclosure_default 
```

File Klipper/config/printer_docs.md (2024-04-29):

### printer.cfg

```
[include mainsail.cfg]
```

<details><summary>mcu</summary>

```
[mcu]
serial: /dev/serial/by-id/usb-Klipper_stm32f446xx_15000E001250335331383820-if00
```
</details>

<details><summary>force_move</summary>

``` 
[force_move]
enable_force_move: True
```
</details>

<details><summary>printer</summary>

``` 

[printer]
kinematics: corexy
max_velocity: 300
max_accel: 3300 #10000                         #Max 4000
max_accel_to_decel: 3300 #10000 #3200                         #Max 4000
max_z_velocity: 15
max_z_accel: 50
square_corner_velocity: 5.0

```
</details>

<details><summary>stepper_x</summary>

``` 
[stepper_x]
##  B Stepper - Left
##      Connected to MOTOR_0
##  Endstop connected to DIAG_0
step_pin: PF13
dir_pin: PF12
enable_pin: !PF14
rotation_distance: 40
microsteps: 16
full_steps_per_rotation:400  #set to 400 for 0.9 degree stepper
endstop_pin: PG6
position_min: 0
position_endstop: 350
position_max: 350
       
##--------------------------------------------------------------------
homing_speed: 25   #Max 100
homing_retract_dist: 5
homing_positive_dir: true

```
</details>

<details><summary>tmc2209 stepper_x</summary>

``` 

##      Make sure to update below for your relevant driver (2208 or 2209)
[tmc2209 stepper_x]
uart_pin: PC4
interpolate: True
run_current: 1.05 #0.9
hold_current: 0.7
sense_resistor: 0.110
stealthchop_threshold: 0

```
</details>

<details><summary>stepper_y</summary>

``` 

[stepper_y]
##  A Stepper - Right
##  Connected to MOTOR_1
##  Endstop connected to DIAG_1
step_pin: PG0
dir_pin: PG1
enable_pin: !PF15
rotation_distance: 40
microsteps: 16
full_steps_per_rotation:400  #set to 400 for 0.9 degree stepper
endstop_pin: PG9
position_min: 0
position_endstop: 0
position_max: 550
homing_speed: 25  #Max 100
homing_retract_dist: 5
homing_positive_dir: false

```
</details>

<details><summary>tmc2209 stepper_y</summary>

``` 

##      Make sure to update below for your relevant driver (2208 or 2209)
[tmc2209 stepper_y]
uart_pin: PD11
interpolate: True
run_current: 1.05 #0.9
hold_current: 0.7
sense_resistor: 0.110
stealthchop_threshold: 0

```
</details>

<details><summary>stepper_z</summary>

``` 

#####################################################################
#       Z Stepper Settings
#####################################################################

## Z0 Stepper - Left Z Motor
## Z Stepper Socket
##  Endstop connected to DIAG_2
[stepper_z]
step_pin: PF11
dir_pin: !PG3
enable_pin: !PG5
homing_positive_dir: false
# Rotation Distance for TR8x8 = 8, TR8x4 = 4, TR8x2 = 2
rotation_distance: 4
microsteps: 32
full_steps_per_rotation: 200    #200 for 1.8 degree, 400 for 0.9 degree
endstop_pin: PG10
## All builds use same Max Z
position_max: 250
position_min: -2.5
position_endstop = -0.050
##--------------------------------------------------------------------
homing_speed: 8.0 # Leadscrews are slower than 2.4, 10 is a recommended max.
second_homing_speed: 3
homing_retract_dist: 3

```
</details>

<details><summary>tmc2209 stepper_z</summary>

``` 

##      Make sure to update below for your relevant driver (2208 or 2209)
[tmc2209 stepper_z]
uart_pin: PC6
interpolate: true
run_current: 0.8
hold_current: 0.5
sense_resistor: 0.110
stealthchop_threshold: 0

```
</details>

<details><summary>stepper_z1</summary>

``` 

##      Z1 Stepper - Rear Z Motor
##      E0 Stepper Socket
[stepper_z1]
step_pin: PG4
dir_pin: !PC1
enable_pin: !PA0
## Remember to mirror these changes in stepper_z and stepper_z2! (there are three motors)
rotation_distance: 4
microsteps: 32
full_steps_per_rotation: 200    #200 for 1.8 degree, 400 for 0.9 degree

```
</details>

<details><summary>tmc2209 stepper_z1</summary>

``` 

##      Make sure to update below for your relevant driver (2208 or 2209)
[tmc2209 stepper_z1]
uart_pin: PC7
interpolate: true
run_current: 0.8
hold_current: 0.5
sense_resistor: 0.110
stealthchop_threshold: 0

```
</details>

<details><summary>stepper_z2</summary>

``` 

##      Z2 Stepper - Right Rear Z Motor
##      E1 Stepper Socket
[stepper_z2]
step_pin: PF9
dir_pin: PF10
enable_pin: !PG2
## Remember to mirror these changes in stepper_z and stepper_z1! (there are three motors)
rotation_distance: 4
microsteps: 32
full_steps_per_rotation: 200    #200 for 1.8 degree, 400 for 0.9 degree

```
</details>

<details><summary>tmc2209 stepper_z2</summary>

``` 

[tmc2209 stepper_z2]
uart_pin: PF2
interpolate: true
run_current: 0.8
hold_current: 0.5
sense_resistor: 0.110
stealthchop_threshold: 0

```
</details>

<details><summary>probe</summary>

``` 

[probe]
pin: PG12
x_offset: 0
y_offset: 25.0
z_offset: -3
speed: 10.0
samples: 3
samples_result: median
sample_retract_dist: 3.0
samples_tolerance: 0.006
samples_tolerance_retries: 3

```
</details>

<details><summary>heater_bed</summary>

``` 

#####################################################################
#   Bed Heater
#####################################################################

[heater_bed]
heater_pin: PA1
sensor_type: Generic 3950
sensor_pin: PF3
max_power: 0.6
min_temp: 0
max_temp: 120
control: pid
pid_kp: 58.437
pid_ki: 2.347
pid_kd: 363.769

```
</details>

<details><summary>homing_override</summary>

``` 

#####################################################################
#   Homing override
#####################################################################

[homing_override]
axes: xyz
gcode:
    {% set home_all = 'X' not in params and 'Y' not in params and 'Z' not in params %}
    {% if home_all or 'Y' in params %}
        G28 Y
    {% endif %}
    {% if home_all or 'X' in params %}
        G28 X
    {% endif %}
    G0 X103 Y334 F6000
    {% if home_all or 'Z' in params %}
        G28 Z
    {% endif %}

```
[include toolchanger.cfg]
```

```
</details>

<details><summary>z_tilt</summary>

``` 

[z_tilt]
z_positions:
    -50, 340
    405,340
    405,-24
points:
       40, 5
       165, 265
       290, 5
speed: 300
horizontal_move_z: 10
retries: 5
retry_tolerance: 0.01250

```
</details>

<details><summary>bed_mesh</summary>

``` 

[bed_mesh]
speed: 300
horizontal_move_z: 5
mesh_min: 30,20
mesh_max: 290,265
fade_end: 10.0
probe_count: 5,5
algorithm: bicubic
zero_reference_position:150,150
#relative_reference_index: 12

```
</details>

```
[include macros.cfg]
```

#*# <---------------------- SAVE_CONFIG ---------------------->
#*# DO NOT EDIT THIS BLOCK OR BELOW. The contents are auto-generated.
#*#

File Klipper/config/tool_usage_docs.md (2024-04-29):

#######################
# TOOL_USAGE_COUNT _ Used to determine first usage of a tool for purge purposes
#######################

<details><summary>TOOL_USE_COUNT</summary>

```  
[gcode_macro TOOL_USE_COUNT]
variable_t0_use_count:0
variable_t1_use_count:0
variable_total_use_count:0
variable_current_nozzle_prime:0
gcode:
```

</details>

<details><summary>INITIALIZE_TOOL_USE_COUNT</summary>

```

[gcode_macro INITIALIZE_TOOL_USE_COUNT]
gcode:
        SET_GCODE_VARIABLE MACRO=TOOL_USE_COUNT VARIABLE=t0_use_count VALUE=0
        SET_GCODE_VARIABLE MACRO=TOOL_USE_COUNT VARIABLE=t1_use_count VALUE=0
        SET_GCODE_VARIABLE MACRO=TOOL_USE_COUNT VARIABLE=total_use_count VALUE=0
        SET_GCODE_VARIABLE MACRO=TOOL_USE_COUNT VARIABLE=current_nozzle_prime VALUE=0

```

</details>

<details><summary>INCREMENT_TOOL_USE_COUNT</summary>

```
[gcode_macro INCREMENT_TOOL_USE_COUNT]
gcode:
        #{% if printer.idle_timeout.state != "Printing" %}
                SET_GCODE_VARIABLE MACRO=TOOL_USE_COUNT VARIABLE=t{params.T}_use_count VALUE={printer["gcode_macro TOOL_USE_COUNT"]['t'~params.T~'_use_count']|int + 1}
                SET_GCODE_VARIABLE MACRO=TOOL_USE_COUNT VARIABLE=total_use_count VALUE={printer["gcode_macro TOOL_USE_COUNT"]['total_use_count']|int + 1}
        #{% endif %}

```

</details>

<details><summary>GET_TOOL_USE_COUNTS</summary>

```

[gcode_macro GET_TOOL_USE_COUNTS]
gcode:

        M118 TOOL CHANGE COUNTS::
        M118 T0 - {printer["gcode_macro TOOL_USE_COUNT"]['t0_use_count']}
        M118 T1 - {printer["gcode_macro TOOL_USE_COUNT"]['t1_use_count']}
        M118 TOTAL - {printer["gcode_macro TOOL_USE_COUNT"]['total_use_count']}
```

</details>
~

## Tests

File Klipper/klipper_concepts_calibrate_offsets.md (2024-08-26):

This starts by calling the macro NUDGE_FIND_TOOLOFFSETS

## TOOL_CALIBRATE_QUERY_PROBE ##
This checks the probe state

## NUDGE_FIND_TOOLOFFSETS ##
```
[gcode_macro NUDGE_FIND_TOOL_OFFSET]
gcode:
  NUDGE_MOVE_OVER_PROBE
  TOOL_LOCATE_SENSOR
```

## NUDGE_MOVE_OVER_PROBE ##
This macro is where you put the nudge location. Eventually it would be good to this into the variables.cfg

```
[gcode_macro NUDGE_MOVE_OVER_PROBE]
gcode:      
  G0 Z2 F500
  # Put your specific values here!
  # Update them too, after the first run.
  G0 X230 F9000
  G0 Y322 F9000
```

## TOOL_LOCATE_SENSOR ##

This calls the python script tools_calibrate.py (located in klipper/klippy/extras/) 

```
# Nozzle alignment module for 3d kinematic probes.
#                                          
# This module has been adapted from code written by Kevin O'Connor <kevin@koconnor.net> and Martin Hierholzer <martin@hierholzer.info>
# Sourced from https://github.com/ben5459/Klipper_ToolChanger/blob/master/probe_multi_axis.py
        
import logging
direction_types = {'x+': [0, +1], 'x-': [0, -1], 'y+': [1, +1], 'y-': [1, -1],
                   'z+': [2, +1], 'z-': [2, -1]}
        
HINT_TIMEOUT = """
If the probe did not move far enough to trigger, then
consider reducing/increasing the axis minimum/maximum
position so the probe can travel further (the minimum
position can be negative).
"""         
            
class ToolsCalibrate:
    def __init__(self, config):
        self.printer = config.get_printer()
        self.name = config.get_name() # gets the [tools_calibrate] data 
        self.gcode_move = self.printer.load_object(config, "gcode_move")
        self.probe = self.printer.lookup_object("probe") # is not needed
        self.probe_multi_axis = PrinterProbeMultiAxis(config, ProbeEndstopWrapper(config,'x'),
                                 ProbeEndstopWrapper(config, 'y'),
                                 ProbeEndstopWrapper(config, 'z'))
        self.probe_name = config.get('probe', 'probe')
        self.travel_speed = config.getfloat('travel_speed', 10.0, above=0.)
        self.spread = config.getfloat('spread', 5.0)
        self.lower_z = config.getfloat('lower_z', 0.5)
        self.lift_z = config.getfloat('lift_z', 1.0)
        self.trigger_to_bottom_z = config.getfloat('trigger_to_bottom_z', default=0.0)
        self.lift_speed = config.getfloat('lift_speed', self.probe_multi_axis.lift_speed)
        self.final_lift_z = config.getfloat('final_lift_z', 4.0)
        self.sensor_location = None
        self.last_result = [0.,0.,0.]
        self.last_probe_offset = 0.
        
        # Register commands
        self.gcode = self.printer.lookup_object('gcode')
        self.gcode.register_command('TOOL_LOCATE_SENSOR', self.cmd_TOOL_LOCATE_SENSOR,
                                    desc=self.cmd_TOOL_LOCATE_SENSOR_help)
        self.gcode.register_command('TOOL_CALIBRATE_TOOL_OFFSET', self.cmd_TOOL_CALIBRATE_TOOL_OFFSET,
                                    desc=self.cmd_TOOL_CALIBRATE_TOOL_OFFSET_help)
        self.gcode.register_command('TOOL_CALIBRATE_SAVE_TOOL_OFFSET', self.cmd_TOOL_CALIBRATE_SAVE_TOOL_OFFSET,
                                    desc=self.cmd_TOOL_CALIBRATE_SAVE_TOOL_OFFSET_help)
        self.gcode.register_command('TOOL_CALIBRATE_PROBE_OFFSET', self.cmd_TOOL_CALIBRATE_PROBE_OFFSET,
                                    desc=self.cmd_TOOL_CALIBRATE_PROBE_OFFSET_help)
        self.gcode.register_command('TOOL_CALIBRATE_QUERY_PROBE', self.cmd_TOOL_CALIBRATE_QUERY_PROBE,
                                    desc=self.cmd_TOOL_CALIBRATE_QUERY_PROBE_help)
    def probe_xy(self, toolhead, top_pos, direction, gcmd, samples = None):
        offset = direction_types[direction]
        start_pos = list(top_pos)
        start_pos[offset[0]] -= offset[1] * self.spread
        toolhead.manual_move([None, None, top_pos[2]+self.lift_z], self.lift_speed)
        toolhead.manual_move([start_pos[0], start_pos[1], None], self.travel_speed)
        toolhead.manual_move([None, None, top_pos[2]-self.lower_z], self.lift_speed)
        return self.probe_multi_axis.run_probe(direction, gcmd, samples = samples)[offset[0]]

    def calibrate_xy(self, toolhead, top_pos, gcmd, samples = None):
        left_x = self.probe_xy(toolhead, top_pos, 'x+', gcmd, samples = samples)
        right_x = self.probe_xy(toolhead, top_pos, 'x-', gcmd, samples = samples)
        near_y = self.probe_xy(toolhead, top_pos, 'y+', gcmd, samples = samples)
        far_y = self.probe_xy(toolhead, top_pos, 'y-', gcmd, samples = samples)
        return [(left_x + right_x) / 2., (near_y + far_y) / 2.]

    def locate_sensor(self, gcmd):
        toolhead = self.printer.lookup_object('toolhead')
        position = toolhead.get_position()
        downPos = self.probe_multi_axis.run_probe("z-", gcmd, samples = 1)
        center_x, center_y = self.calibrate_xy(toolhead, downPos, gcmd, samples = 1)

        toolhead.manual_move([None, None, downPos[2]+self.lift_z], self.lift_speed)
        toolhead.manual_move([center_x, center_y, None], self.travel_speed)
        center_z = self.probe_multi_axis.run_probe("z-", gcmd, speed_ratio=0.5)[2]
        # Now redo X and Y, since we have a more accurate center.
        center_x, center_y = self.calibrate_xy(toolhead, [center_x, center_y, center_z], gcmd)

        # rest above center
        position[0] = center_x
        position[1] = center_y
        position[2] = center_z+self.final_lift_z
        toolhead.manual_move([None, None, position[2]], self.lift_speed)
        toolhead.manual_move([position[0], position[1], None], self.travel_speed)
        toolhead.set_position(position)
        return [center_x, center_y, center_z]

    cmd_TOOL_LOCATE_SENSOR_help = ("Locate the tool calibration sensor, "
                                  "use with tool 0.")
    def cmd_TOOL_LOCATE_SENSOR(self, gcmd):
        self.last_result = self.locate_sensor(gcmd)
        self.sensor_location = self.last_result
        self.gcode.respond_info("Sensor location at %.6f,%.6f,%.6f"
                                % (self.last_result[0], self.last_result[1], self.last_result[2]))

    cmd_TOOL_CALIBRATE_TOOL_OFFSET_help = "Calibrate current tool offset relative to tool 0"
    def cmd_TOOL_CALIBRATE_TOOL_OFFSET(self, gcmd):
        if not self.sensor_location:
            raise gcmd.error("No recorded sensor location, please run TOOL_LOCATE_SENSOR first")
        location = self.locate_sensor(gcmd)
        self.last_result=[location[i]-self.sensor_location[i] for i in range(3)]
        self.gcode.respond_info("Tool offset is %.6f,%.6f,%.6f"
                                % (self.last_result[0], self.last_result[1], self.last_result[2]))

    cmd_TOOL_CALIBRATE_SAVE_TOOL_OFFSET_help = "Save tool offset calibration to config"
    def cmd_TOOL_CALIBRATE_SAVE_TOOL_OFFSET(self, gcmd):
        if not self.last_result:
            gcmd.error(
                "No offset result, please run TOOL_CALIBRATE_TOOL_OFFSET first")
            return

        param_name = gcmd.get("ATTRIBUTE")
        template = gcmd.get("VALUE", "{x:0.6f}, {y:0.6f}, {z:0.6f}")
        value = template.format(x=self.last_result[0], y=self.last_result[1], z=self.last_result[2])

        save_variables = self.printer.lookup_object('save_variables')
        save_variables.cmd_SAVE_VARIABLE(self.gcode.create_gcode_command("SAVE_VARIABLE", "SAVE_VARIABLE", {"VARIABLE": param_name, 'VALUE': value }))

    cmd_TOOL_CALIBRATE_PROBE_OFFSET_help = "Calibrate the tool probe offset to nozzle tip"
    def cmd_TOOL_CALIBRATE_PROBE_OFFSET(self, gcmd):
        toolhead = self.printer.lookup_object('toolhead')
        probe = self.printer.lookup_object(self.probe_name)
        start_pos = toolhead.get_position()
        nozzle_z = self.probe_multi_axis.run_probe("z-", gcmd, speed_ratio=0.5)[2]
        # now move down with the tool probe
        probe_z = probe.run_probe(gcmd)[2]

        z_offset = probe_z - nozzle_z + self.trigger_to_bottom_z
        self.last_probe_offset = z_offset
        self.gcode.respond_info(
            "%s: z_offset: %.3f\n"
            "The SAVE_CONFIG command will update the printer config file\n"
            "with the above and restart the printer." % (self.probe.name, z_offset))
        config_name = gcmd.get("PROBE", default=self.probe.name)
        if config_name:
            configfile = self.printer.lookup_object('configfile')
            configfile.set(config_name, 'z_offset', "%.6f" % (z_offset,))
        # back to start pos
        toolhead.move(start_pos, self.travel_speed)
        toolhead.set_position(start_pos)

    def get_status(self, eventtime):
        return {'last_result': self.last_result,
                'last_probe_offset': self.last_probe_offset,
                'last_x_result': self.last_result[0],
                'last_y_result': self.last_result[1],
                'last_z_result': self.last_result[2]}

    cmd_TOOL_CALIBRATE_QUERY_PROBE_help = "Return the state of calibration probe"
    def cmd_TOOL_CALIBRATE_QUERY_PROBE(self, gcmd):
        toolhead = self.printer.lookup_object('toolhead')
        print_time = toolhead.get_last_move_time()
        endstop_states = [probe.query_endstop(print_time) for probe in self.probe_multi_axis.mcu_probe] # Check the state of each axis probe (x, y, z)
        self.calibration_probe_inactive = any(endstop_states)
        gcmd.respond_info("Calibration Probe: %s" % (["open", "TRIGGERED"][any(endstop_states)]))

class PrinterProbeMultiAxis:
    def __init__(self, config, mcu_probe_x, mcu_probe_y, mcu_probe_z):
        self.printer = config.get_printer()
        self.name = config.get_name()
        self.mcu_probe = [mcu_probe_x, mcu_probe_y, mcu_probe_z]
        self.speed = config.getfloat('speed', 5.0, above=0.)
        self.lift_speed = config.getfloat('lift_speed', self.speed, above=0.)
        self.max_travel = config.getfloat("max_travel", 4, above=0)
        self.last_state = False
        self.last_result = [0., 0., 0.]
        self.last_x_result = 0.
        self.last_y_result = 0.
        self.last_z_result = 0.
        self.gcode = self.printer.lookup_object('gcode')
        self.gcode_move = self.printer.load_object(config, "gcode_move")

        xconfig = config.getsection('stepper_x')
        yconfig = config.getsection('stepper_y')
        zconfig = config.getsection('stepper_z')
        # Note: This may not work for all kinematics (delta)...
        self.axis_range = [{-1: xconfig.getfloat('position_min', 0.),
                            +1: xconfig.getfloat('position_max')},
                           {-1: yconfig.getfloat('position_min', 0.),
                            +1: yconfig.getfloat('position_max')},
                           {-1: zconfig.getfloat('position_min', 0.),
                            +1: zconfig.getfloat('position_max')}]

        # Multi-sample support (for improved accuracy)
        self.sample_count = config.getint('samples', 1, minval=1)
        self.sample_retract_dist = config.getfloat('sample_retract_dist', 2.,
                                                   above=0.)
        atypes = {'median': 'median', 'average': 'average'}
        self.samples_result = config.getchoice('samples_result', atypes,
                                               'average')
        self.samples_tolerance = config.getfloat('samples_tolerance', 0.100,
                                                 minval=0.)
        self.samples_retries = config.getint('samples_tolerance_retries', 0,
                                             minval=0)
        # Register xyz_virtual_endstop pin
        self.printer.lookup_object('pins').register_chip('probe_multi_axis',
                                                         self)

    def setup_pin(self, pin_type, pin_params):
        if pin_type != 'endstop' or pin_params['pin'] != 'xy_virtual_endstop':
            raise pins.error("Probe virtual endstop only useful as endstop pin")
        if pin_params['invert'] or pin_params['pullup']:
            raise pins.error("Can not pullup/invert probe virtual endstop")
        return self.mcu_probe
    def setup_pin(self, pin_type, pin_params):
        if pin_type != 'endstop' or pin_params['pin'] != 'xy_virtual_endstop':
            raise pins.error("Probe virtual endstop only useful as endstop pin")
        if pin_params['invert'] or pin_params['pullup']:
            raise pins.error("Can not pullup/invert probe virtual endstop")
        return self.mcu_probe

    def get_lift_speed(self, gcmd=None):
        if gcmd is not None:
            return gcmd.get_float("LIFT_SPEED", self.lift_speed, above=0.)
        return self.lift_speed

    def _probe(self, speed, axis, sense):
        toolhead = self.printer.lookup_object('toolhead')
        curtime = self.printer.get_reactor().monotonic()
        if 'x' not in toolhead.get_status(curtime)['homed_axes'] or \
                'y' not in toolhead.get_status(curtime)['homed_axes'] or \
                'z' not in toolhead.get_status(curtime)['homed_axes']:
            raise self.printer.command_error("Must home before probe")
        phoming = self.printer.lookup_object('homing')
        pos = toolhead.get_position()
        pos[axis] = self.axis_range[axis][sense]
        try:
            epos = phoming.probing_move(self.mcu_probe[axis], pos, speed)
        except self.printer.command_error as e:
            reason = str(e)
            if "Timeout during endstop homing" in reason:
                reason += HINT_TIMEOUT
            raise self.printer.command_error(reason)
        # self.gcode.respond_info("probe at %.3f,%.3f is z=%.6f"
        self.gcode.respond_info("Probe made contact at %.6f,%.6f,%.6f"
                                % (epos[0], epos[1], epos[2]))
        return epos[:3]

    def _move(self, coord, speed):
        self.printer.lookup_object('toolhead').manual_move(coord, speed)

    def _calc_mean(self, positions):
        count = float(len(positions))
        return [sum([pos[i] for pos in positions]) / count
                for i in range(3)]

    def _calc_median(self, positions, axis):
        axis_sorted = sorted(positions, key=(lambda p: p[axis]))
        middle = len(positions) // 2
        if (len(positions) & 1) == 1:
            # odd number of samples
            return axis_sorted[middle]
        # even number of samples
        return self._calc_mean(axis_sorted[middle - 1:middle + 1])
    def run_probe(self, direction, gcmd, speed_ratio = 1.0, samples = None):
        speed = gcmd.get_float("PROBE_SPEED", self.speed, above=0.) * speed_ratio
        if direction not in direction_types:
            raise self.printer.command_error("Wrong value for DIRECTION.")

        logging.info("run_probe direction = " + str(direction))

        (axis, sense) = direction_types[direction]

        logging.info("run_probe axis = %d, sense = %d" % (axis, sense))

        lift_speed = self.get_lift_speed(gcmd)
        sample_count = gcmd.get_int("SAMPLES", samples if samples else self.sample_count, minval=1)
        sample_retract_dist = gcmd.get_float("SAMPLE_RETRACT_DIST",
                                             self.sample_retract_dist, above=0.)
        samples_tolerance = gcmd.get_float("SAMPLES_TOLERANCE",
                                           self.samples_tolerance, minval=0.)
        samples_retries = gcmd.get_int("SAMPLES_TOLERANCE_RETRIES",
                                       self.samples_retries, minval=0)
        samples_result = gcmd.get("SAMPLES_RESULT", self.samples_result)

        probe_start = self.printer.lookup_object('toolhead').get_position()
        retries = 0
        positions = []
        while len(positions) < sample_count:
            # Probe position
            pos = self._probe(speed, axis, sense)
            positions.append(pos)
            # Check samples tolerance
            axis_positions = [p[axis] for p in positions]
            if max(axis_positions) - min(axis_positions) > samples_tolerance:
                if retries >= samples_retries:
                    raise gcmd.error("Probe samples exceed samples_tolerance")
                gcmd.respond_info("Probe samples exceed tolerance. Retrying...")
                retries += 1
                positions = []
            # Retract
            if len(positions) < sample_count:
                liftpos = probe_start
                liftpos[axis] = pos[axis] - sense * sample_retract_dist
                self._move(liftpos, lift_speed)
        # Calculate and return result
        if samples_result == 'median':
            return self._calc_median(positions, axis)
        return self._calc_mean(positions)

# Endstop wrapper that enables probe specific features
class ProbeEndstopWrapper:
    def __init__(self, config, axis):
        self.printer = config.get_printer()
        self.axis = axis
        # Create an "endstop" object to handle the probe pin
        ppins = self.printer.lookup_object('pins')
        pin = config.get('pin')
        ppins.allow_multi_use_pin(pin.replace('^', '').replace('!', ''))
        pin_params = ppins.lookup_pin(pin, can_invert=True, can_pullup=True)
        mcu = pin_params['chip']
        self.mcu_endstop = mcu.setup_pin('endstop', pin_params)
        self.printer.register_event_handler('klippy:mcu_identify',
                                            self._handle_mcu_identify)
        # Wrappers
        self.get_mcu = self.mcu_endstop.get_mcu
        self.add_stepper = self.mcu_endstop.add_stepper
        self.get_steppers = self.mcu_endstop.get_steppers
        self.home_start = self.mcu_endstop.home_start
        self.home_wait = self.mcu_endstop.home_wait
        self.query_endstop = self.mcu_endstop.query_endstop

    def _handle_mcu_identify(self):
        kin = self.printer.lookup_object('toolhead').get_kinematics()
        for stepper in kin.get_steppers():
            if stepper.is_active_axis(self.axis):
                self.add_stepper(stepper)

    def get_position_endstop(self):
        return 0.

def load_config(config):
    return ToolsCalibrate(config)
                                                                                                                                                               334,1         Bot

```

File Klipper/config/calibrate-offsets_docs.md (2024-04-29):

<details><summary>tools_calibrate</summary>

```
[tools_calibrate]
pin: PG12
travel_speed: 100
spread: 7
lower_z: 1.0
# The speed (in mm/sec) to move tools down onto the probe
speed: 1
# The speed (in mm/sec) to retract between probes
lift_speed: 4
final_lift_z: 6
samples:3
samples_result: median # median, average
sample_retract_dist:3
samples_tolerance:0.02
samples_tolerance_retries:3
# Decrease -> higher nozzle
trigger_to_bottom_z: 3
```
</details>

<details><summary>CALIBRATE_MOVE_OVER_PROBE</summary>

```
[gcode_macro _CALIBRATE_MOVE_OVER_PROBE]
gcode:
    BED_MESH_CLEAR
    G0 Z62 F10000
    G0 X342.5 Y18.5 F10000
```
</details>

<details><summary>CALIBRATE_MOVE_OVER_PROBE</summary>

```
[gcode_macro _CALIBRATE_MOVE_OVER_PROBE_PARAMS]
    gcode:
        BED_MESH_CLEAR
        G0 Z63 F10000
        G0 X{params.Y} Y{params.Y} F10000
```
</details>

<details><summary>CALIBRATE_TOOL_OFFSETS</summary>

```
[gcode_macro CALIBRATE_TOOL_OFFSETS]
gcode:
    {% set tools = [0,1,2,3,4] %}
    T_1
    T{tools[0]}
    _CALIBRATE_MOVE_OVER_PROBE    
    TOOL_LOCATE_SENSOR
    
    {% for tool in tools[1:] %}
        M118 T{tool} Offset Calculation Begin
        T{tool}
        _CALIBRATE_MOVE_OVER_PROBE
        TOOL_CALIBRATE_TOOL_OFFSET
        TOOL_CALIBRATE_SAVE_TOOL_OFFSET ATTRIBUTE="t{tool}_x_offset" VALUE="{% raw %}{x:0.6f}{% endraw %}"
        TOOL_CALIBRATE_SAVE_TOOL_OFFSET ATTRIBUTE="t{tool}_y_offset" VALUE="{% raw %}{y:0.6f}{% endraw %}"
        TOOL_CALIBRATE_SAVE_TOOL_OFFSET ATTRIBUTE="t{tool}_z_offset" VALUE="{% raw %}{z:0.6f}{% endraw %}"
        M118 T{tool} Offset Calculation End
    {% endfor %}
    
    T{tools[0]}

```
</details>

<details><summary>CALIBRATE_TOOL_OFFSETS</summary>

```    
[gcode_macro CALIBRATE_TOOL_OFFSETS]
    gcode:

        G32                
        {% for iteration in range(25) %}
            G28
            _CALIBRATE_MOVE_OVER_PROBE    
            TOOL_LOCATE_SENSOR
        {% endfor %}

```
</details>

<details><summary>_PICK_TOOL_AND_LOCATE_SENSOR</summary>

```    
[gcode_macro _PICK_TOOL_AND_LOCATE_SENSOR]
        gcode:
            T_1
            T{params.T}
            _CALIBRATE_MOVE_OVER_PROBE    
            TOOL_LOCATE_SENSOR
            T_1
```
</details>

<details><summary>CHECK_TOOL_REPEATABILITY</summary>

```    
[gcode_macro CHECK_TOOL_REPEATABILITY]
    gcode:
    
        G32  
        {% for iteration in range(5) %}
            T{params.T}
            _CALIBRATE_MOVE_OVER_PROBE    
            TOOL_LOCATE_SENSOR
            KTCC_TOOL_DROPOFF_ALL
        {% endfor %}
```
</details>

<details><summary>CALIBRATE_OFFSETS_TEST</summary>

```    
[gcode_macro CALIBRATE_OFFSETS_TEST]
    gcode:
    
        G32
    
        {% set cal_loop = [0,1,2,3,4,5] %}
        {% set tools = [0,1] %}
        
        {% for iteration in range(25)%}
        
            T{tools[0]}
            _CALIBRATE_MOVE_OVER_PROBE    
            TOOL_LOCATE_SENSOR
            
            {% for tool in tools[1:] %}
                T{tool}
                _CALIBRATE_MOVE_OVER_PROBE
                TOOL_CALIBRATE_TOOL_OFFSET
                TOOL_CALIBRATE_SAVE_TOOL_OFFSET ATTRIBUTE="i{iteration}_t{tool}_x_offset" VALUE="{% raw %}{x:0.6f}{% endraw %}"
                TOOL_CALIBRATE_SAVE_TOOL_OFFSET ATTRIBUTE="i{iteration}_t{tool}_y_offset" VALUE="{% raw %}{y:0.6f}{% endraw %}"
                TOOL_CALIBRATE_SAVE_TOOL_OFFSET ATTRIBUTE="i{iteration}_t{tool}_z_offset" VALUE="{% raw %}{z:0.6f}{% endraw %}"
            {% endfor %}
        {% endfor %}
        
        T{tools[0]}
```
</details>

<details><summary>CALIBRATE_ONE_OFFSET</summary>

```    
[gcode_macro CALIBRATE_ONE_OFFSET]
gcode:
    {% set tools = printer.toolchanger.tool_numbers %}
    {% set names = printer.toolchanger.tool_names %}
    # Tool 0
    SELECT_TOOL T=0  RESTORE_AXIS=XYZ
    STOP_TOOL_PROBE_CRASH_DETECTION
    _CLEAN_NOZZLE TEMP=220
    _CALIBRATE_MOVE_OVER_PROBE    
    M104 S150
    TOOL_LOCATE_SENSOR
    M104 S0
    SELECT_TOOL T={params.TOOL}  RESTORE_AXIS=Z
    STOP_TOOL_PROBE_CRASH_DETECTION
    _CLEAN_NOZZLE TEMP=220
    M104 S150 T{params.TOOL}
    _CALIBRATE_MOVE_OVER_PROBE    
    TOOL_CALIBRATE_TOOL_OFFSET
    TOOL_CALIBRATE_PROBE_OFFSET PROBE="tool_probe T{params.TOOL}"
    M104 S0
    
    # Finish up
    SELECT_TOOL T=0 RESTORE_AXIS=XYZ
```
</details>

<details><summary>CALIBRATE_NOZZLE_PROBE_OFFSET</summary>

```
[gcode_macro CALIBRATE_NOZZLE_PROBE_OFFSET]
gcode:
    STOP_TOOL_PROBE_CRASH_DETECTION
    _CLEAN_NOZZLE TEMP=220
    _CALIBRATE_MOVE_OVER_PROBE
    M104 S150
    TEMPERATURE_WAIT SENSOR='{printer.toolhead.extruder}' MINIMUM=150
    TOOL_LOCATE_SENSOR
    TOOL_CALIBRATE_PROBE_OFFSET PROBE="tool_probe T0"
    M104 S0
```

</details>

<details><summary>TEST_TOOL_OFFSET</summary>

```    
[gcode_macro TEST_TOOL_OFFSET]
gcode:
    T_1
    T{params.T}
    SET_GCODE_OFFSET X_ADJUST={params.OFFSET_X|float} Y_ADJUST={params.OFFSET_Y|float} Z={params.OFFSET_Z|float}
    G1 X{params.X} Y{params.Y} Z{params.Z} F10000

```
</details>

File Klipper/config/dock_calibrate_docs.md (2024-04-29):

### doc_calibrate.cfg - Calibrate dock positions

<details><summary>doc_calibrate</summary>

```
[dock_calibrate]
dock_calibrate_move_1_gcode:
        SET_KINEMATIC_POSITION X=50 Y=350
        G91
        G1 X-14 F3000
        G1 X2 F3000
dock_calibrate_move_2_gcode:
        G28 Y
        G28 X

rod_install_msg_gcode:
        {% set msg = "Please install the tool locking rods back into the dock. The printer will pause for 20 seconds for you to finish this step" %}
        M117 {msg}
        RESPOND TYPE=command MSG="{msg}"
        G4 P20000

dock_test_gcode:
        SET_GCODE_VARIABLE MACRO=STORE_TOOLHEAD_POSITION VARIABLE=bypass_toolhead_position VALUE=1
        SET_KINEMATIC_POSITION X=10 Y=10 Z=50
        G28 Y
        G28 X
        G90
        {% for move in range(5) %}
                KTCC_TOOL_DROPOFF_ALL
                T{printer["gcode_macro VARIABLES_LIST"].active_tool}
        {% endfor %}
xy_resolution: 0.003125
dock_extra_offset_x_unlock:0.5
dock_extra_offset_y_unlock:0.2
dock_extra_offset_x_lock:0.5
dock_extra_offset_y_lock:0.8
```

</details>

<details><summary>DOCK_TEST_MANUAL</summary>

```
[gcode_macro DOCK_TEST_MANUAL]
gcode:
        G28
        G90
        {% for move in range(5) %}
                KTCC_TOOL_DROPOFF_ALL
                T{printer["gcode_macro VARIABLES_LIST"].active_tool}
        {% endfor %}
```

</details>

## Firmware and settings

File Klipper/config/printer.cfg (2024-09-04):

# This file contains common pin mappings for the BigTreeTech GTR.
# To use this config, the firmware should be compiled for the
# STM32F407 with a "32KiB bootloader".

# The "make flash" command does not work on the GTR. Instead,
# after running "make", copy the generated "klipper/out/klipper.bin" file to a
# file named "firmware.bin" on an SD card and then restart the GTR
# with that SD card.

# See docs/Config_Reference.md for a description of parameters.

[gcode_macro DUMP_PARAMS]
gcode:
  {action_respond_info(rawparams)}

[include fluidd.cfg]
#[include adxl.cfg]

#[skew_correction]

[exclude_object]
[respond]

[gcode_arcs]

[force_move]
enable_force_move=1


[input_shaper]

[pause_resume]

[display_status]

[exclude_object]

[virtual_sdcard]
path: /home/pi/printer_data/gcodes

[display_status]

[pause_resume]


#[gcode_macro _CLIENT_VARIABLE]
#gcode:
#  variable_use_custom_pos: True
#  variable_custom_park_x: 150.0  # Adjust this value
#  variable_custom_park_y: 10.0   # Adjust this value
#  variable_custom_park_dz: 2.0   # Adjust if needed
#  variable_speed_move: 100.0    # Move speed in mm/s


[gcode_macro _CLIENT_VARIABLE]
variable_use_custom_pos   : True ; use custom park coordinates for x,y [True/False]
variable_custom_park_x    : 20.0   ; custom x position; value must be within your defined min and max of X
variable_custom_park_y    : 20.0   ; custom y position; value must be within your defined min and max of Y
variable_custom_park_dz   : 2.0   ; custom dz value; the value in mm to lift the nozzle when move to park position
variable_retract          : 1.0   ; the value to retract while PAUSE
variable_cancel_retract   : 5.0   ; the value to retract while CANCEL_PRINT
variable_speed_retract    : 35.0  ; retract speed in mm/s
variable_unretract        : 1.0   ; the value to unretract while RESUME
variable_speed_unretract  : 35.0  ; unretract speed in mm/s
variable_speed_hop        : 15.0  ; z move speed in mm/s
variable_speed_move       : 100.0 ; move speed in mm/s
variable_park_at_cancel   : False ; allow to move the toolhead to park while execute CANCEL_PRINT [True/False]
variable_park_at_cancel_x : None  ; different park position during CANCEL_PRINT [None/Position as Float]; park_at_cancel must be True
variable_park_at_cancel_y : None  ; different park position during CANCEL_PRINT [None/Position as Float]; park_at_cancel must be True
## !!! Caution [firmware_retraction] must be defined in the printer.cfg if you set use_fw_retract: True !!!
variable_use_fw_retract   : False ; use fw_retraction instead of the manual version [True/False]
variable_idle_timeout     : 0     ; time in sec until idle_timeout kicks in. Value 0 means that no value will be set or restored
variable_runout_sensor    : ""    ; If a sensor is defined, it will be used to cancel the execution of RESUME in case no filament is detected.
##                                   Specify the config name of the runout sensor e.g "filament_switch_sensor runout". Hint use the same as in your printer.cfg
## !!! Custom macros, please use with care and review the section of the corresponding macro.
## These macros are for simple operations like setting a status LED. Please make sure your macro does not interfere with the basic macro functions.
## Only  single line commands are supported, please create a macro if you need more than one command.
variable_user_pause_macro : ""    ; Everything inside the "" will be executed after the klipper base pause (PAUSE_BASE) function
variable_user_resume_macro: ""    ; Everything inside the "" will be executed before the klipper base resume (RESUME_BASE) function
variable_user_cancel_macro: ""    ; Everything inside the "" will be executed before the klipper base cancel (CANCEL_PRINT_BASE) function
gcode:









[mcu]
serial: /dev/serial/by-id/usb-Klipper_stm32f446xx_15000E001250335331383820-if00

[printer]
max_velocity: 400
max_accel: 12000
kinematics: corexy
max_z_velocity: 300
max_z_accel: 400
square_corner_velocity: 5.0


[input_shaper]
shaper_freq_x: 38.2
shaper_type_x: ei
shaper_freq_y: 34.8
shaper_type_y: mzv


[include motors.cfg]

[tool_probe_endstop]

[include calibrate-offsets.cfg]

[fan_generic RSCS]
##  RSCS Fans - In FAN1 Positon
pin: PD13
max_power: 1
shutdown_speed: 0
kick_start_time: 0.1
off_below: 0.10

[controller_fan driver_fan]
pin:PD12
max_power:0.5
shutdown_speed: 0
kick_start_time: 0.1
off_below: 0.10
stepper:stepper_x, stepper_y


#####################################################################
#   Bed Heater
#####################################################################

[heater_bed]
##  SSR Pin - HE1
##  Thermistor - TB
heater_pin: PA1
## Check what thermistor type you have. See https://www.klipper3d.org/Config_Reference.html#common-thermistors for common thermistor types.
## Use "Generic 3950" for Keenovo heaters
sensor_type: Generic 3950
sensor_pin: PF3
##  Adjust max_power so it doesn't exceed the SSR rating. The Omron G3NA-210B-DC5 SSR is rated at 4 amps without a heatsink.
##  The formula is "4 / (Wattage_of_bed_heater / Mains_voltage) = max_power"
##  If max_power is greater than 1.0, use 1.0
max_power: 0.6
min_temp: 0
max_temp: 120
control: pid
pid_kp: 58.437
pid_ki: 2.347
pid_kd: 363.769

[verify_heater heater_bed]
max_error: 180
check_gain_time: 180
heating_gain: 2

#####################################################################
#       Probe
#####################################################################



#######################################
#### Enclosure Temp Sensor Section ####
#######################################

[temperature_sensor raspberry_pi]
sensor_type: temperature_host
min_temp: 10
max_temp: 100

[temperature_sensor octopus]
sensor_type: temperature_mcu
min_temp: 10
max_temp: 100

[neopixel cled]
##      To control Neopixel RGB in mini12864 display
pin: PB6
chain_count:60
initial_RED: 1
initial_GREEN: 1
initial_BLUE: 1
color_order:GRB

[idle_timeout]
timeout: 1800

[homing_override]
axes: z
set_position_z: 0
gcode:
    {% if printer["gcode_macro VARIABLES_LIST"].tc_state|int == 0 %}
      G90
      G0 Z10 F250
      G0 X200 Y380 F6000
      G28 Z0
      G0 Z25 F250
      G0 X200 Y250 F6000
    {% else %}
      M118 "Tool Changer in error state. Unable to continue."
    {% endif %}

[z_tilt]
#xmin: -65
#xmax: 485
#ymin: -95
#ymax: 455 
z_positions:
    -65,-95
    -65,455
    455,-95
    455,455
    #210,455


points:
    30,20
    #30,280
    365,20
    #365,280
    175,280



speed: 50
horizontal_move_z: 20
retries: 5
retry_tolerance: 0.01250


[bed_mesh]
speed: 100
horizontal_move_z: 12
mesh_min: 30,50
mesh_max: 340,290
fade_end: 10.0
probe_count: 5,5
algorithm: bicubic
zero_reference_position:170,145
#relative_reference_index: 12


[include gcode_macros.cfg]

[include toolchanger.cfg]

#*# <---------------------- SAVE_CONFIG ---------------------->
#*# DO NOT EDIT THIS BLOCK OR BELOW. The contents are auto-generated.
#*#
#*# [extruder]
#*#
#*# [extruder1]
#*#
#*# [bed_mesh default]
#*# version = 1
#*# points =
#*# 	  -0.166788, 0.113212, 0.209462, 0.048837, -0.221163
#*# 	  -0.108038, -0.003663, 0.090087, -0.108663, -0.383038
#*# 	  0.003212, -0.061163, -0.049288, -0.274288, -0.453038
#*# 	  0.085087, -0.034913, -0.091163, -0.371163, -0.624288
#*# 	  0.135087, -0.037413, -0.235538, -0.480538, -0.766163
#*# x_count = 5
#*# y_count = 5
#*# mesh_x_pps = 2
#*# mesh_y_pps = 2
#*# algo = bicubic
#*# tension = 0.2
#*# min_x = 30.0
#*# max_x = 340.0
#*# min_y = 50.0
#*# max_y = 290.0
#*#
#*# [bed_mesh 80.0C]
#*# version = 1
#*# points =
#*# 	-0.219518, -0.117599, -0.074781, -0.090461, -0.223136
#*# 	-0.122423, -0.051261, 0.041612, 0.019298, -0.079002
#*# 	-0.150768, -0.051261, 0.000000, 0.044024, -0.074178
#*# 	-0.232785, -0.186952, -0.124836, -0.169463, -0.262336
#*# 	-0.446272, -0.371491, -0.329879, -0.380537, -0.578344
#*# x_count = 5
#*# y_count = 5
#*# mesh_x_pps = 2
#*# mesh_y_pps = 2
#*# algo = bicubic
#*# tension = 0.2
#*# min_x = 15.0
#*# max_x = 310.0
#*# min_y = 15.0
#*# max_y = 270.0
#*#
#*# [bed_mesh 65.0C]
#*# version = 1
#*# points =
#*# 	0.045379, -0.034226, -0.082472, -0.008897, 0.014020
#*# 	-0.007691, -0.022165, 0.022463, 0.014020, 0.156344
#*# 	0.033318, 0.056234, -0.007691, 0.182879, 0.302287
#*# 	0.057441, -0.010103, 0.023669, 0.190116, 0.345708
#*# 	-0.157252, -0.153634, -0.035432, 0.111717, 0.214239
#*# x_count = 5
#*# y_count = 5
#*# mesh_x_pps = 2
#*# mesh_y_pps = 2
#*# algo = bicubic
#*# tension = 0.2
#*# min_x = 30.0
#*# max_x = 290.0
#*# min_y = 20.0
#*# max_y = 265.0

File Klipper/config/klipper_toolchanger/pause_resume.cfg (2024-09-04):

[gcode_macro SET_PAUSE_TYPE]
gcode:
	SET_GCODE_VARIABLE MACRO=VARIABLES_LIST VARIABLE=pause_type VALUE={params.TYPE}
	
[gcode_macro RESET_PAUSE_TYPE]
gcode:
	SET_GCODE_VARIABLE MACRO=VARIABLES_LIST VARIABLE=pause_type VALUE=0



	

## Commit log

2024-03-15 Create load_eject.calibrate.py
    This is a script that creates the load and eject macro for a given tool.
2024-04-29 Update and rename calibrate-offsets.cfg to calibrate-offsets_docs.md
2024-07-08 Create CAN_setup
    The recipe for setting up CAN board
2025-04-14 Create raspberrypi_wifi.md
    How to use a raspberry pi camera toolhead as an alternative to can
